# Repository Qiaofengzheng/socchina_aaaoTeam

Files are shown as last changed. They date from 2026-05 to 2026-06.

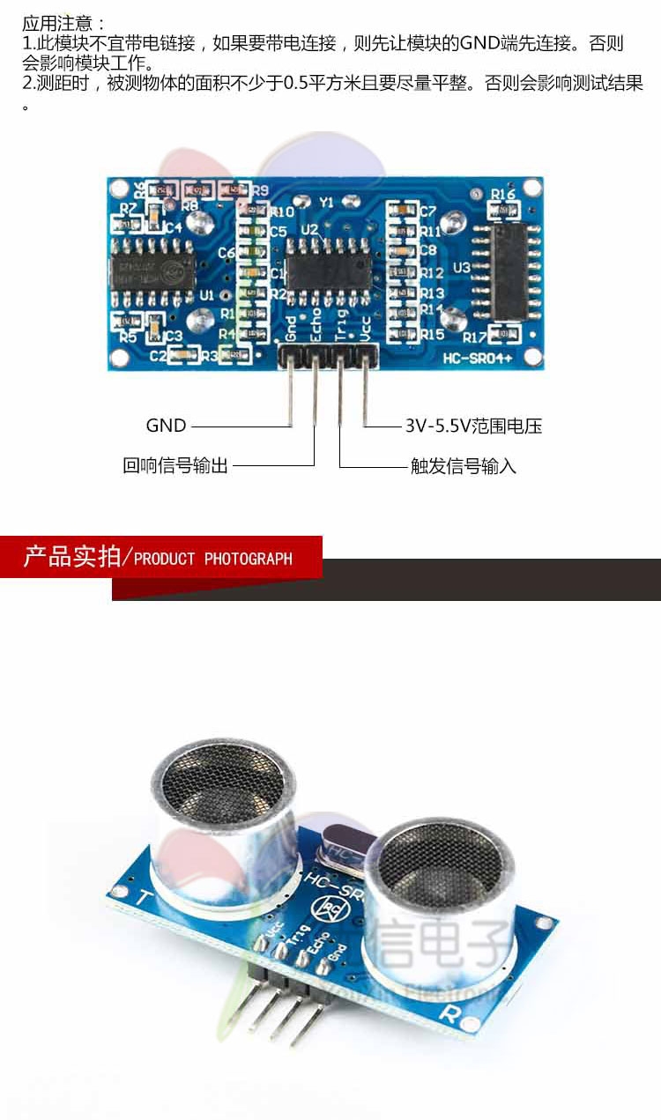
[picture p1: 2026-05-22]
竞赛资料/主控资料-ch32v307/CH32V307例程/2.24-HC-SR04超声波测距/2.24-HC-SR04超声波测距/2.jpg

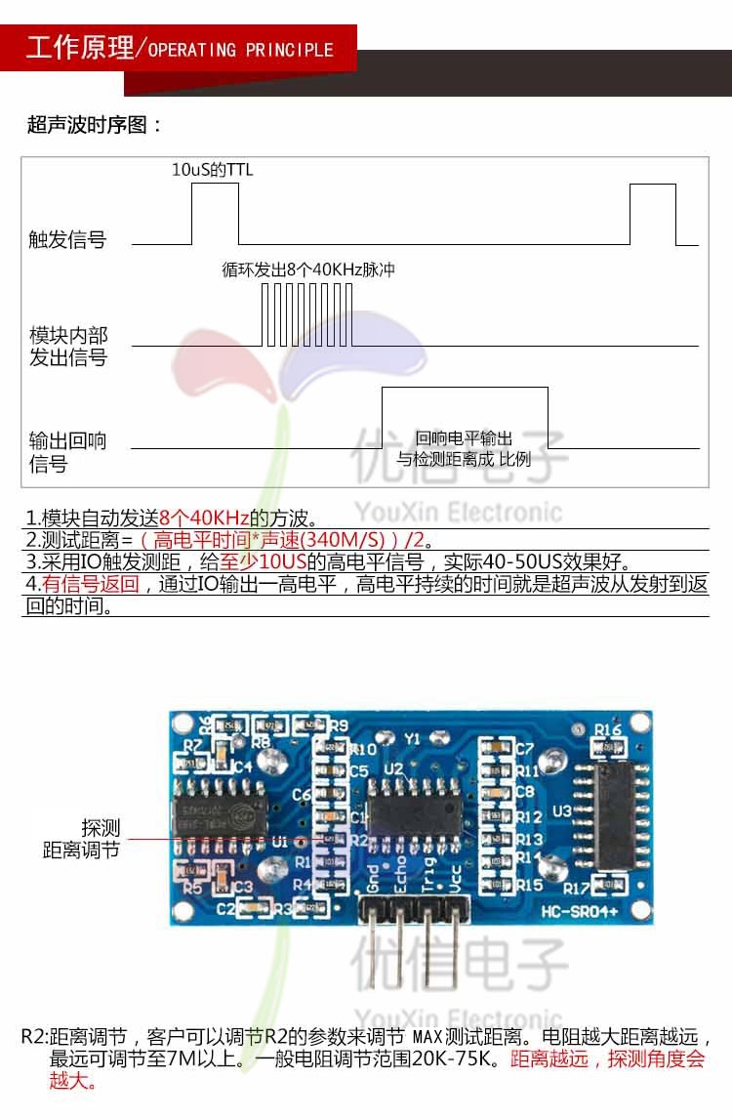
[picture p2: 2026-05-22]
竞赛资料/主控资料-ch32v307/CH32V307例程/2.24-HC-SR04超声波测距/2.24-HC-SR04超声波测距/1.jpg

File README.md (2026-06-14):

<div align="center">

# 🎥 基于CH32V307的稳像云台控制系统

### Multi-Modal Stabilized Gimbal Control System Based on CH32V307


[]()
[]()
[]()

*🏆 SOC China · AAAO Team*

---

## 📖 项目简介

本作品基于沁恒 **CH32V307** 核心板，设计了一款面向智能拍摄与辅助科技场景的**多模态交互三自由度稳像云台系统**。

系统通过摄像头实时采集图像，采用轻量化卷积神经网络实现**手势识别**与**人脸检测**，触发三自由度云台控制。创新性地集成**语音指令控制模块**与**低功耗蓝牙通信模块**，构建手势+语音+视觉的多模态人机交互体系，并采用**增量式PID算法**实现三轴舵机的精准控制。硬件上集成高扭矩舵机、OLED状态反馈模块、语音模块、低功耗蓝牙通信模块及独立电源，依托CH32V307的外设资源，通过多组UART串口实现识别指令与舵机控制的高效交互。创新点在于多模态指令映射、三轴协同控制、语音-视觉跨模态控制技术及低功耗边缘计算架构，适用于需要非接触控制的智能拍摄场景，以及益于特殊人群的辅助科技应用，兼具高实用性与可扩展性。

<div align="center">

### 🌟 核心亮点

| 🤚 手势控制 | 🗣️ 语音控制 | 👁️ 视觉跟踪 | 📱 蓝牙控制 |
|:---:|:---:|:---:|:---:|
| MediaPipe手势识别 | LD3320语音识别 | OpenCV人脸检测 | CH9141低功耗蓝牙 |
| 支持数字1-7及握拳 | 非接触语音指令 | 实时人脸追踪 | 手机APP远程控制 |

</div>

---

## 💡 项目背景与设计动机

### 为什么做这个项目？

在当今数字化时代，**摄像设备的智能化控制**已成为一个重要的技术方向。传统的云台控制方式——无论是手持遥控器还是手机APP——都要求操作者与设备保持物理接触或近距离操作。然而，在许多实际场景中，这种传统的交互方式存在明显的局限性：

1. **影视拍摄场景**：摄影师在进行多机位拍摄时，双手往往被其他设备占用，无法同时操控云台；在需要特殊角度拍摄时，操作者可能需要远离设备以获得更好的观察视角。

2. **无障碍辅助场景**：对于肢体残障人士而言，传统的按键式或触屏式交互方式可能无法使用。他们迫切需要一种**非接触式、直觉化**的人机交互方式来操控辅助设备。

3. **工业巡检场景**：在高温、高辐射、有毒等危险环境中，操作人员需要在安全距离外远程操控检测设备，传统的有线控制方式存在线缆束缚和信号延迟的问题。

4. **教育科研场景**：嵌入式系统、计算机视觉、控制理论等课程需要一个综合性的实践平台，让学生能够将理论知识应用于实际系统。

### 设计理念

基于上述需求分析，我们确立了以下设计原则：

- **多模态融合**：不依赖单一交互方式，而是同时支持手势、语音、视觉、蓝牙四种控制模式，用户可以根据场景灵活选择最合适的方式。
- **边缘计算优先**：将计算密集型任务（如图像识别）交给PC端处理，实时控制任务（如PID运算、舵机驱动）由嵌入式端完成，实现"边缘-云端"协同计算。
- **模块化架构**：硬件和软件均采用模块化设计，便于后期功能扩展和维护升级。
- **实时性保证**：关键控制路径采用中断驱动，确保从传感器输入到执行器输出的延迟最小化。

---

## 🏗️ 系统架构

### 总体架构设计

整个系统采用**分层架构**设计，自上而下分为三个层次：**感知决策层**（Python上位机）、**控制执行层**（CH32V307嵌入式系统）、**机械执行层**（三轴舵机云台）。各层之间通过标准化的串口协议进行数据交换，实现了高内聚、低耦合的系统架构。

```
+-------------------------------------------------------------------------+
|                   Python Upper Computer (PC)                            |
|                                                                         |
|  +----------------+  +----------------+  +----------------+            |
|  |   MediaPipe    |  |    OpenCV      |  |  Serial Comm   |            |
|  | Gesture Recog  |  | Face Detection |  | 3-Ch Parallel  |            |
|  | 21 Key Points  |  | Haar Cascade   |  | COM22/20/9     |            |
|  +--------+-------+  +--------+-------+  +--------+-------+            |
|           +------------------+--------------------+                      |
+-----------------------------------+--------------------------------------+
                                    | USB-UART
                                    v
+-------------------------------------------------------------------------+
|                 CH32V307 Embedded Control Layer                         |
|                                                                         |
|  +----------+  +----------+  +----------+  +----------+               |
|  |   UART   |  |   PID    |  |   PWM    |  |   GPIO   |               |
|  | Multi-Prt|--| 3-Axis   |--| Servo Drv|  |  Sensors |               |
|  |  Router  |  | Control  |  | 50Hz/3ch |  | ADC/GPIO |               |
|  +----------+  +----------+  +----------+  +----------+               |
|                                                                         |
|  +----------+  +----------+  +----------+  +----------+               |
|  |  Voice   |  |Bluetooth |  |   TFT    |  |  Buzzer  |               |
|  |  LD3320  |  |  CH9141  |  | Display  |  | + LED    |               |
|  +----------+  +----------+  +----------+  +----------+               |
+-------------------------------------------------------------------------+
                                    |
                                    v PWM 50Hz
+-------------------------------------------------------------------------+
|                      Mechanical Actuator Layer                          |
|                                                                         |
|       +--------------+  +--------------+  +--------------+             |
|       | X-Axis Servo |  | Y-Axis Servo |  | Z-Axis Servo |             |
|       |  PA0 (TIM2)  |  |  PA1 (TIM2)  |  |  PA2 (TIM2)  |             |
|       +--------------+  +--------------+  +--------------+             |
|                                                                         |
|                      +-------------------+                              |
|                      | 3-Axis Gimbal     |                              |
|                      | Stabilized Plat.  |                              |
|                      +-------------------+                              |
+-------------------------------------------------------------------------+
```

---

## 🎯 功能特性

### 🤚 多模态手势识别

手势识别是本系统最核心的交互方式之一。我们采用 Google 的 **MediaPipe** 框架作为手势识别引擎，该框架基于轻量化的卷积神经网络，能够在普通PC上实现实时的21点手部关键点检测。

**识别原理详解：**

MediaPipe 首先从视频帧中检测手部区域，然后定位21个手部关键点（包括指尖、指关节、手掌中心等）。通过分析这些关键点的空间位置关系，我们可以判断每根手指是否伸出：

- 对于拇指：比较指尖（关键点4）与拇指根部（关键点2）的水平位置关系
- 对于其他四指：比较指尖与对应掌指关节的垂直位置关系
- 如果指尖在手掌凸包外部，则认为该手指处于"伸出"状态

通过组合不同手指的伸出状态，系统可以识别出多种手势。为了提高识别的鲁棒性，我们还加入了**稳定性检测**机制：连续3帧识别到相同手势才确认为有效手势，避免因手部抖动导致的误识别。

支持 **7种手势** 识别，每种手势映射不同控制指令：

```
    +--------------------+
    |   Camera Input     |
    |  640x480 @ 30fps   |
    +--------+-----------+
             |
             v
    +--------------------+
    |   MediaPipe        |
    | Gesture Recognition|
    |   21 Key Points    |
    +--------+-----------+
             |
     +-------+-------+-------+
     |               |       |
     v               v       v
+----------+   +----------+  +----------+
|  Digit   |   |  Fist    |  |  Five    |
| 1/2/3/4  |   |  (Stop)  |  | (Track)  |
|  6/7     |   |          |  |          |
+----+-----+   +----+-----+  +----+-----+
     |              |             |
     v              v             v
 Manual Ctrl   Stop Motion    Start Face
 +/-5 deg                   Tracking Mode
```

**手势-功能映射表：**

| 手势 | 功能 | 云台动作 | 识别条件 |
|:---:|:---:|:---:|:---:|
| ☝️ 数字 `1` | X轴正转 | 水平向右 +5° | 仅食指伸出，关节角度>160° |
| ✌️ 数字 `2` | X轴反转 | 水平向左 -5° | 食指+中指伸出 |
| 🤟 数字 `3` | Y轴正转 | 垂直向上 +5° | 拇指+食指+中指伸出，指尖距离>60px |
| 🖐️ 数字 `4` | Y轴反转 | 垂直向下 -5° | 四指伸出（除小指） |
| 🖐️ 数字 `5` | 启动追踪 | 开启人脸跟踪模式 | 五指全部伸出 |
| 🤙 数字 `6` | Z轴正转 | 航向顺时针 +5° | 拇指+小指伸出（"打电话"手势） |
| 🤏 数字 `7` | Z轴反转 | 航向逆时针 -5° | 拇指+食指+中指伸出，指尖距离<60px |
| ✊ 握拳 `fist` | 停止 | 停止所有运动 | 无手指伸出 |

**防抖动与可靠性设计：**

由于手势识别存在一定的不确定性，我们在通信层面加入了多重保障机制：

1. **稳定性窗口**：连续3帧相同手势才触发指令发送
2. **冷却时间**：手势切换后需等待500ms才能触发下一次切换
3. **重复发送**：每个手势指令重复发送4次，确保嵌入式端能够接收到
4. **变化阈值**：人脸坐标变化超过5°才发送，减少通信负载

### 👁️ 智能人脸追踪

人脸追踪是本系统的另一核心功能。当用户做出"五指张开"手势或通过语音指令激活追踪模式后，系统会自动锁定摄像头画面中的人脸，并驱动云台跟随人脸运动，使人脸始终保持在画面中心区域。

**技术实现细节：**

1. **人脸检测**：采用 OpenCV 内置的 **Haar级联分类器**（`haarcascade_frontalface_default.xml`），这是一种经典的基于特征的机器学习检测方法。虽然近年来深度学习方法在准确率上有所超越，但Haar级联在嵌入式场景下具有**速度快、资源占用少**的优势，非常适合实时应用。

2. **目标选择策略**：当画面中存在多张人脸时，系统选择**面积最大的人脸**作为跟踪目标，这通常是距离摄像头最近、也是最可能需要被拍摄的主体。

3. **坐标映射算法**：将人脸中心的像素坐标转换为云台舵机的目标角度。具体来说：
   - 图像中心（320, 240）对应云台的中位角度（94°）
   - 人脸偏离图像中心越远，舵机需要偏转的角度越大
   - 映射公式：`angle = 94 - (center - image_center) * (86 / image_center)`

4. **平滑滤波**：为了消除人脸检测结果的帧间抖动，我们采用**5点移动平均滤波器**。具体做法是维护一个长度为5的滑动窗口，将最近5帧的人脸坐标取平均值作为最终输出。这样即使某一帧的检测结果存在偏差，也不会导致云台的突然跳动。

5. **三轴协同补偿**：在跟踪人脸时，不仅X轴和Y轴需要跟随运动，Z轴（航向）也需要进行协同补偿。当人脸偏向画面左侧时，Z轴需要顺时针旋转以获得更好的拍摄角度；反之亦然。补偿公式为：`z_compensation = norm_x × 20 + norm_y × 5`。

```
    +-------------------+
    | Gesture '5'       |
    | Five Fingers Open |
    +---------+---------+
              |
              v
    +-------------------+       +------------------+
    | Activate Tracking | <---- | Voice Command    |
    | Mode              |       | LD3320 Recognize |
    +---------+---------+       +------------------+
              |
              v
    +-------------------+
    |  Haar Cascade     |
    |  Face Detector    |
    +---------+---------+
              |
              v
    +-------------------+
    | Select Largest    |
    | Face Center (x,y) |
    +---------+---------+
              |
              v
    +-------------------+
    | Coord Mapping     |
    | Pixel -> Angle    |
    +---------+---------+
              |
              v
    +-------------------+
    | 5-Point Moving    |
    | Avg Smoothing     |
    +---------+---------+
              |
              v
    +-------------------+
    | 3-Axis PID Ctrl   |
    +---------+---------+
              |
              v
    +-------------------+
    | Servo Actuation   |
    | Gimbal Follow     |
    +-------------------+
```

### 🔊 语音控制系统

语音控制模块为系统提供了第三种交互维度。通过集成**LD3320**语音识别芯片，用户可以在不使用双手的情况下，通过简单的语音指令控制云台的行为。

**工作原理：**

LD3320是一款专用的语音识别芯片，内置了非特定人语音识别引擎（即不需要对特定用户进行训练）。芯片通过UART串口与CH32V307通信，当识别到预设的语音关键词后，会通过串口发送对应的识别码。

**系统中的语音控制流程：**

1. 用户说出语音指令（如"开始追踪"）
2. LD3320芯片识别语音，通过UART5发送识别结果给CH32V307
3. CH32V307接收到识别结果后，通过UART4转发给Python上位机
4. Python上位机收到指令后，启动或关闭人脸追踪模式

这种**语音→嵌入式→PC**的跨层级控制链路，实现了语音-视觉的跨模态融合控制。

```
    +----------------+
    |  Voice Input   |
    | 'Start Tracking'|
    +-------+--------+
            |
            v
    +----------------+
    |   LD3320       |
    | Voice Recog    |
    +-------+--------+
            |
            v
    +----------------+
    |    UART5       |
    | Intpt Receive  |
    +-------+--------+
            |
            v
    +----------------+
    |    UART4       |
    | Fwd to Python  |
    +-------+--------+
            |
            v
    +----------------+
    |    Python      |
    | Activate Track |
    +----------------+
```

### 📱 蓝牙远程控制

通过集成**CH9141**低功耗蓝牙模块，系统支持手机APP远程控制。用户可以通过蓝牙连接，实时查看传感器数据、调整控制参数、切换工作模式。

**蓝牙通信协议：**

蓝牙模块通过UART6与CH32V307通信，采用简单的命令-响应协议：

| 命令码 | 功能描述 |
|:---:|:---|
| `1` | 查看CO气体浓度（MQ7传感器） |
| `2` | 查看天然气浓度（MQ4传感器） |
| `3` | 查看测距数据 |
| `5` | 查看温度数据 |
| `6` | 查看湿度数据 |
| `7` | 当前模式阈值 -1 |
| `8` | 当前模式阈值 +1 |
| `9` | 全部传感器数据上报 |

蓝牙模块每500ms通过TIM10定时中断自动读取一次数据，确保控制指令的及时响应。

---

## 🛠️ 硬件配置

### 核心芯片选型

本系统选用**CH32V307VCT6**作为主控芯片，这是沁微科技推出的一款基于**RISC-V**架构的32位通用微控制器。选择该芯片主要基于以下考量：

1. **高性能**：主频高达144MHz，能够满足实时控制的计算需求
2. **丰富的外设**：集成了多路UART、SPI、I2C、ADC、PWM等外设，无需额外扩展芯片
3. **充足的存储**：256KB Flash + 64KB SRAM，为复杂的控制算法提供了足够的运行空间
4. **开源生态**：RISC-V架构具有开放的指令集和丰富的社区资源，便于开发和调试
5. **成本优势**：相比同级别的ARM芯片，CH32V307具有更好的性价比

<table>
  <tr>
    <td><b>主控芯片</b></td>
    <td>CH32V307VCT6 (RISC-V, 144MHz)</td>
  </tr>
  <tr>
    <td><b>系统时钟</b></td>
    <td>144 MHz</td>
  </tr>
  <tr>
    <td><b>Flash</b></td>
    <td>256 KB</td>
  </tr>
  <tr>
    <td><b>SRAM</b></td>
    <td>64 KB</td>
  </tr>
  <tr>
    <td><b>舵机驱动</b></td>
    <td>3路PWM (TIM2, 50Hz, 0.5ms-2.5ms)</td>
  </tr>
  <tr>
    <td><b>通信接口</b></td>
    <td>5路UART + SPI + I2C + ADC</td>
  </tr>
</table>

### 完整硬件清单

| 类别 | 型号/规格 | 数量 | 用途说明 |
|:---:|:---|:---:|:---|
| 🔲 主控板 | CH32V307VCT6 核心板 | 1 | 系统主控制器，运行所有嵌入式程序 |
| ⚙️ 舵机 | MG996R 高扭矩舵机 | 3 | X/Y/Z三轴驱动，扭矩11kg·cm |
| 📷 摄像头 | USB摄像头 (640×480@30fps) | 1 | 手势识别和人脸检测的视觉输入 |
| 🔊 语音模块 | LD3320 语音识别模块 | 1 | 非特定人语音识别，UART接口 |
| 📡 蓝牙模块 | CH9141 低功耗蓝牙模块 | 1 | 手机APP远程控制，UART接口 |
| 🖥️ 显示屏 | TFT180 (128×160) | 1 | 系统状态显示、坐标信息反馈 |
| 🔔 蜂鸣器 | 有源蜂鸣器 | 1 | 操作提示音、报警信号 |
| 💡 LED指示灯 | 直插LED | 2 | 系统状态指示 |
| 🔥 火焰传感器 | 红外火焰传感器 | 1 | 火焰检测（GPIO输入） |
| 🌫️ 气体传感器 | MQ2/MQ4/MQ7 | 3 | 烟雾/天然气/CO浓度检测（ADC输入） |
| 🔌 电源模块 | 5V/3A 开关电源 | 1 | 系统供电 |

### 引脚分配图

```
                            CH32V307VCT6
                         ┌────────────────┐
            UART1_TX ◀──┤PA9         PA0├──▶ X-Servo  (TIM2_CH1)
            UART1_RX ◀──┤PA10        PA1├──▶ Y-Servo  (TIM2_CH2)
                        ┤PA2         PA2├──▶ Z-Servo  (TIM2_CH3)
            UART8_TX ◀──┤PC4         PA4├──▶ Buzzer
            UART8_RX ◀──┤PC5         PA3├──◀ Flame Sensor
                        ┤              ├
           UART4_TX  ◀──┤PC10        PB0├──◀ ADC Sensor 1
           UART4_RX  ◀──┤PC11        PB1├──◀ ADC Sensor 2
           UART5_TX  ◀──┤PC12        PC0├──◀ ADC Sensor 3
           UART5_RX  ◀──┤PD2         PC1├──◀ ADC Sensor 4
           UART6_TX  ◀──┤PE10        PC2├──◀ ADC Sensor 5
           UART6_RX  ◀──┤PE11        PC3├──◀ ADC Sensor 6
                        ┤              ├
             SPI_CS  ◀──┤PA4         PB13├──▶ SPI_SCK
           SPI_MOSI  ◀──┤PB15        PB6├──▶ I2C_SCL (PCA9685)
                        ┤PB7         PB7├──▶ I2C_SDA (PCA9685)
                        ┤              ├
            LED_1    ◀──┤PC13       PB10├──▶ LED_2
                        └────────────────┘
```

### UART 串口分配

本系统的一个显著特点是使用了**5路UART串口**进行并行通信，每路串口负责不同的通信任务。这种设计虽然增加了硬件复杂度，但实现了各通信通道的**独立性和实时性**，避免了单总线通信可能带来的数据冲突和延迟问题。

<table>
  <thead>
    <tr>
      <th>串口</th>
      <th>波特率</th>
      <th>TX</th>
      <th>RX</th>
      <th>用途</th>
      <th>详细说明</th>
    </tr>
  </thead>
  <tbody>
    <tr>
      <td><b>UART_4</b></td>
      <td>115200</td>
      <td>PC10</td>
      <td>PC11</td>
      <td>🖥️ Python主通信</td>
      <td>与PC端Python程序的主通信通道，传输手势指令和语音触发信号</td>
    </tr>
    <tr>
      <td><b>UART_5</b></td>
      <td>9600</td>
      <td>PC12</td>
      <td>PD2</td>
      <td>🔊 语音识别模块</td>
      <td>连接LD3320语音识别芯片，接收语音识别结果</td>
    </tr>
    <tr>
      <td><b>UART_6</b></td>
      <td>115200</td>
      <td>PE10</td>
      <td>PE11</td>
      <td>👁️ 人脸坐标接收</td>
      <td>接收Python发送的人脸坐标数据，格式为"X,Y\n"</td>
    </tr>
    <tr>
      <td><b>UART_8</b></td>
      <td>9600</td>
      <td>PC4</td>
      <td>PC5</td>
      <td>🗣️ 语音控制模块</td>
      <td>连接外部语音控制模块，接收语音控制指令</td>
    </tr>
    <tr>
      <td><b>UART_1</b></td>
      <td>19200</td>
      <td>PA9</td>
      <td>PA10</td>
      <td>📡 调试/反馈</td>
      <td>用于调试信息输出和温度数据反馈</td>
    </tr>
  </tbody>
</table>

---

## 💻 软件架构

### 代码结构

整个项目的代码按照功能模块划分为清晰的目录结构，遵循**高内聚、低耦合**的设计原则：

```
📁 CH32V307 的稳像云台控制系统/
├── 📄 README.md                    # 项目说明文档
├── 📄 .gitignore                   # Git忽略配置
│
├── 📁 竞赛资料/
│   ├── 📁 代码/
│   │   ├── 📄 识别.py              # 🐍 Python上位机 (504行)
│   │   │                              负责手势识别、人脸检测、串口通信
│   │   │
│   │   ├── 📄 语音控制.hd           # 🔊 语音控制配置文件
│   │   │
│   │   └── 📁 ch32v307代码/
│   │       ├── 📁 libraries/       # 📚 SDK库文件 (第三方)
│   │       │   ├── zf_common/      #   通用工具库 (延时、调试等)
│   │       │   ├── zf_device/      #   设备驱动库 (摄像头、屏幕等)
│   │       │   └── zf_driver/      #   底层驱动库 (UART、PWM、GPIO等)
│   │       │
│   │       └── 📁 project/
│   │           ├── 📁 code/        # 📝 用户核心代码 (17个源文件)
│   │           │   ├── main.c           # 程序入口，主循环
│   │           │   ├── duoji.c/h        # 舵机控制、命令处理
│   │           │   ├── pid.c/h          # PID控制算法
│   │           │   ├── contorl.c/h      # 控制逻辑、数据处理
│   │           │   ├── bluetooth.c/h    # 蓝牙通信控制
│   │           │   ├── ironhand.c/h     # 多串口数据路由
│   │           │   ├── init.c/h         # 系统初始化
│   │           │   ├── servo.c/h        # PWM舵机驱动
│   │           │   ├── adc.c/h          # ADC多通道采集
│   │           │   ├── beep.c/h         # 蜂鸣器驱动
│   │           │   ├── led.c/h          # LED驱动
│   │           │   ├── spi.c/h          # 软件SPI驱动
│   │           │   ├── myiic.c/h        # 模拟I2C驱动
│   │           │   ├── pca9685.c/h      # PCA9685驱动 (备用)
│   │           │   ├── temp.c/h         # 内部温度传感器
│   │           │   ├── light_sensor.c/h # 光照传感器 (预留)
│   │           │   └── font.h           # 字体字模数据
│   │           │
│   │           └── 📁 user/
│   │               └── 📁 src/
│   │                   ├── main.c       # 主程序入口
│   │                   └── isr.c        # 中断服务程序 (489行)
│   │
│   └── 📁 主控资料-ch32v307/         # 芯片数据手册、参考设计
│
└── 📁 项目介绍/
    ├── 📄 作品报告.pdf               # 详细技术报告
    └── 📄 演示视频.mp4               # 系统演示视频
```

### 模块功能说明

#### 核心模块详解

| 模块 | 文件 | 代码行数 | 核心职责 |
|:---:|:---:|:---:|:---|
| **主程序** | `main.c` | 55 | 系统初始化、主循环调度 |
| **舵机控制** | `duoji.c` | 282 | 三轴舵机角度控制、手势命令处理、平滑移动算法 |
| **PID控制** | `pid.c` | 50 | 增量式PID算法实现（备用，当前使用分段比例控制） |
| **控制逻辑** | `contorl.c` | 431 | 坐标解析、数据滤波、蓝牙数据发送、传感器采集 |
| **蓝牙通信** | `bluetooth.c` | 158 | CH9141蓝牙模块控制、命令状态机 |
| **多串口路由** | `ironhand.c` | 245 | 5路UART数据接收、语音命令转发 |
| **中断服务** | `isr.c` | 489 | UART/Timer/EXTI中断处理 |
| **系统初始化** | `init.c` | 48 | 外设初始化、参数配置 |
| **舵机驱动** | `servo.c` | 28 | PWM信号生成、角度-脉宽转换 |
| **Python上位机** | `识别.py` | 504 | MediaPipe手势识别、OpenCV人脸检测、串口通信 |

---

## 🧮 核心算法详解

### 1️⃣ PID控制算法

PID（比例-积分-微分）控制是工业控制中最经典的算法之一。本系统为X/Y/Z三个轴分别配置了独立的PID控制器，每个轴的参数根据其运动特性进行了专门调校。

**算法公式：**

```
    误差(error) = 目标角度 - 当前角度
    
    P (比例项) = Kp × error
        → 对误差进行比例响应，误差越大响应越强
    
    I (积分项) = Ki × Σerror (带积分限幅)
        → 消除稳态误差，当|error|<10°时才累积积分
        → 当|error|≥10°时清零积分，防止积分饱和
    
    D (微分项) = Kd × (error - prev_error)
        → 预测误差变化趋势，抑制超调和振荡
    
    输出 = P + I + D (带输出限幅)
```

**三轴PID参数配置：**

| 轴 | Kp | Ki | Kd | 积分限幅 | 输出限幅 | 设计意图 |
|:---:|:---:|:---:|:---:|:---:|:---:|:---|
| X轴 | 1.2 | 0.04 | 0.1 | 30.0 | 10.0 | 快速响应，适配水平旋转的低惯量特性 |
| Y轴 | 0.8 | 0.03 | 0.2 | 40.0 | 8.0 | 平稳移动，避免垂直方向的重力影响导致抖动 |
| Z轴 | 0.8 | 0.05 | 0.2 | 20.0 | 5.0 | 精确控制，航向微调需要更高的精度 |

### 2️⃣ 分段比例控制（实际使用）

在实际调试中，我们发现对于本系统的舵机响应特性，**分段比例控制**比完整的PID控制更加适合。这是因为：

1. 舵机本身具有位置保持能力，不需要积分项来消除稳态误差
2. 舵机的响应速度有限，微分项的预测作用不明显
3. 分段控制可以根据误差大小自动切换响应速度，更加符合人机交互的直觉

**分段策略：**

```
+---------------------------------------------------------------+
|               Segmented Proportional Control                  |
+---------------------------------------------------------------+
|                                                               |
|   |error| > 20   =>  step = error / 2   (Fast Chase)         |
|                     Large error: full speed toward target     |
|                                                               |
|   |error| > 5    =>  step = error / 3   (Medium Speed)       |
|                     Medium error: slow down to avoid overshoot|
|                                                               |
|   |error| <= 5   =>  step = +/-1        (Fine Tune)          |
|                     Small error: adjust by 1 deg per cycle    |
|                                                               |
+---------------------------------------------------------------+
```

这种分段策略的优点是：**大误差时快速响应，小误差时精细控制**，既保证了系统的动态性能，又提高了定位精度。

### 3️⃣ 三轴协同控制算法

在人脸跟踪模式下，三个轴不是独立运动的，而是需要协同配合。特别是Z轴（航向），需要根据X/Y轴的偏移量进行补偿，以获得最佳的拍摄角度。

**协同补偿公式：**

```
    X-Axis Offset --+
                    |
                    +--> Z-Axis Compensation = norm_x * 20 + norm_y * 5
    Y-Axis Offset --+

    Where:
    - norm_x = (face_x - 135) / 135.0  (normalized to [-1, 1])
    - norm_y = (face_y - 120) / 120.0  (normalized to [-1, 1])
    - Z-Axis initial angle = 40 deg
    - Compensation coefficients 20 and 5 tuned by field testing
```

### 4️⃣ 语音-视觉跨模态控制

本系统的一个创新点是实现了**语音-视觉跨模态控制**。用户可以通过语音指令激活视觉追踪模式，然后系统自动切换到人脸跟踪控制，实现"语音触发、视觉执行"的无缝切换。

```
    Voice Command --> Activate Visual Tracking --> Face Detection --> Gimbal Follow
        |
        +--> "Start Tracking" --> Python starts tracking mode
            "Stop Tracking"  --> Close tracking mode
```

### 5️⃣ 低功耗边缘计算架构

本系统采用"边缘-云端"协同计算架构，将不同计算需求的任务分配到最合适的计算节点：

```
+-------------------------------------------+
|        Edge Node (CH32V307)                |
|                                            |
|   144MHz RISC-V Processor                  |
|   ├── PID Control (realtime, <1ms)         |
|   ├── Sensor Data Acquisition (realtime)   |
|   ├── Serial Data Routing (realtime)       |
|   └── PWM Servo Drive (50Hz)               |
|                                            |
|        Cloud Node (PC)                     |
|                                            |
|   Python + GPU Acceleration                |
|   ├── MediaPipe Gesture (~30ms/frame)      |
|   ├── OpenCV Face Detection (~20ms/frame)  |
|   └── Image Preprocessing & Coord Calc     |
|                                            |
+-------------------------------------------+
```

这种架构的优势在于：
- **实时性**：嵌入式端专注于实时控制，不受图像处理延迟的影响
- **灵活性**：PC端可以随时更新识别算法，无需重新烧录固件
- **可扩展性**：未来可以将图像识别算法移植到嵌入式端，实现完全独立运行

---

## 📡 通信协议详解

### Python ↔ CH32V307 通信协议

Python上位机与CH32V307之间通过3路串口并行通信，每路串口承载不同的数据类型：

| 通信方向 | 串口 | 数据格式 | 示例 | 说明 |
|:---:|:---:|:---|:---|:---|
| Python → MCU | COM22 | `{数字}\n` | `"5\n"` | 手势指令（1-7, 0=停止） |
| Python → MCU | COM20 | `{X},{Y}\n` | `"94,120\n"` | 人脸坐标（角度值） |
| MCU → Python | COM9 | `5` | `'5'` | 语音触发信号 |

### 手势指令编码

| 指令码 | ASCII | 手势 | 云台动作 |
|:---:|:---:|:---:|:---|
| `0` | 0x30 | 握拳 | 停止所有运动 |
| `1` | 0x31 | 数字1 | X轴 +5° |
| `2` | 0x32 | 数字2 | X轴 -5° |
| `3` | 0x33 | 数字3 | Y轴 +5° |
| `4` | 0x34 | 数字4 | Y轴 -5° |
| `5` | 0x35 | 数字5 | 启动人脸追踪 |
| `6` | 0x36 | 数字6 | Z轴 +5° |
| `7` | 0x37 | 数字7 | Z轴 -5° |

---

## 📱 应用场景

### 🎬 智能拍摄

在影视制作、直播、Vlog拍摄等场景中，操作者可以通过手势或语音控制摄像头的拍摄角度，无需接触任何控制设备。特别是当摄影师需要同时操控多个机位时，多模态控制的优势尤为突出。

**典型使用流程：**
1. 摄影师做出"五指张开"手势，激活人脸追踪模式
2. 摄像头自动锁定目标人物，云台跟随其运动
3. 需要调整拍摄角度时，通过语音指令"左转"、"右转"进行微调
4. 拍摄结束后，做出"握拳"手势，停止所有运动

### 🏥 辅助科技

对于肢体残障人士，传统的交互方式可能无法使用。本系统提供的非接触式控制方式，为他们打开了一扇新的窗户。

**无障碍应用场景：**
- 手指轻微活动即可控制云台方向
- 语音指令替代复杂的按键操作
- 人脸追踪实现"看哪拍哪"的直觉式控制

### 🎓 教学实验

本系统涵盖了嵌入式系统、计算机视觉、控制理论、通信协议等多个领域的知识点，非常适合作为综合性课程设计或毕业设计的实践平台。

**可学习的知识点：**
- RISC-V架构与嵌入式C编程
- PID控制算法原理与调参
- 串口通信协议设计
- 计算机视觉基础（手势识别、人脸检测）
- 多传感器数据融合

---

## ⚡ 快速开始

### 环境要求

| 工具 | 版本要求 | 用途 |
|:---|:---|:---|
| MounRiver Studio | V1.8.1+ | 嵌入式代码编译与烧录 |
| Python | 3.8+ | 上位机运行环境 |
| OpenCV | 4.5+ | 图像处理库 |
| MediaPipe | 0.8+ | 手势识别框架 |
| PySerial | 3.5+ | 串口通信库 |

### 1. 硬件连接

按照上述引脚分配图完成硬件连接，特别注意：
- 三路舵机分别连接PA0/PA1/PA2
- 各UART模块的TX/RX需要交叉连接
- 确保电源供电充足（舵机工作电流较大）

### 2. 嵌入式端编译与烧录

```bash
# 1. 打开 MounRiver Studio
# 2. 导入项目: 竞赛资料/代码/ch32v307代码/project
# 3. 编译项目 (Build)
# 4. 连接开发板，烧录固件
```

### 3. Python上位机运行

```bash
# 1. 安装依赖
pip install opencv-python mediapipe pyserial numpy

# 2. 修改串口配置（根据实际设备号）
# 在 识别.py 中修改：
#   serial_hand = init_serial('COM22', 9600)   # 手势串口
#   serial_face = init_serial('COM20', 115200) # 人脸串口
#   serial_mcu  = init_serial('COM9', 115200)  # MCU通信串口

# 3. 运行程序
python 识别.py
```

### 4. 操作说明

1. 系统启动后，摄像头窗口自动打开
2. 在摄像头前做出手势，观察云台响应
3. 做出"五指张开"手势激活人脸追踪
4. 做出"握拳"手势停止所有运动
5. 按'q'键退出程序

---

## 📊 技术指标

| 指标 | 数值 | 说明 |
|:---|:---|:---|
| 系统时钟 | 144 MHz | CH32V307主频 |
| 图像分辨率 | 640×480 | 摄像头采集分辨率 |
| 视频帧率 | 30 fps | 摄像头采集帧率 |
| 手势识别延迟 | ~100ms | 3帧确认时间 |
| 人脸检测延迟 | ~30ms | 单帧检测时间 |
| PID控制周期 | 20ms | 嵌入式端控制频率 |
| 数据发送周期 | 100ms | Python端发送频率 |
| 舵机PWM频率 | 50Hz | 标准舵机控制频率 |
| 舵机角度范围 | 0°-180° | 三轴统一范围 |
| 蓝牙通信距离 | ~10m | 低功耗蓝牙有效距离 |

---

## 🗺️ 未来改进方向

| 方向 | 具体措施 | 预期效果 |
|:---|:---|:---|
| 🧠 边缘AI | 将手势识别算法移植到嵌入式端 | 脱离PC独立运行 |
| 📷 更换摄像头 | 使用OV2640等嵌入式摄像头 | 降低系统成本 |
| 🔋 电池供电 | 加入锂电池管理模块 | 实现便携式使用 |
| 🌐 WiFi控制 | 替换蓝牙为WiFi模块 | 扩大控制距离 |
| 📊 数据可视化 | 开发专用APP实时显示传感器数据 | 提升用户体验 |
| 🤖 自动构图 | 基于AI的智能构图算法 | 自动调整拍摄角度 |

---

## 📋 Git 提交规范

本项目遵循以下 Git 提交规范，确保代码版本管理的清晰和可追溯：

| 类型 | 说明 | 示例 |
|:---:|:---|:---|
| `feat` | 新功能 | `feat: 添加蓝牙远程控制功能` |
| `fix` | Bug修复 | `fix: 修复UART6数据接收丢包问题` |
| `docs` | 文档更新 | `docs: 更新README项目说明` |
| `refactor` | 代码重构 | `refactor: 优化PID控制算法结构` |
| `perf` | 性能优化 | `perf: 减少串口通信延迟` |
| `test` | 测试相关 | `test: 添加舵机角度映射单元测试` |
| `chore` | 构建/工具 | `chore: 更新.gitignore配置` |

**提交信息格式：**
```
<type>: <简短描述>

<详细说明（可选）>

<相关Issue编号（可选）>
```

---

## 🐛 已知问题与改进方向

| 类别 | 问题描述 | 影响 | 改进方案 |
|:---:|:---|:---:|:---|
| 🐛 Bug | `adc_data`数组越界（声明5元素，访问[5]） | 高 | 修改数组大小为6 |
| 🐛 Bug | `contorl.c`文件名拼写错误 | 低 | 重命名为`control.c` |
| 🧹 清理 | 大量注释代码未清理 | 低 | 删除或使用条件编译 |
| 🧹 清理 | `STC11XX.H`与CH32V307无关 | 低 | 移除冗余文件 |
| 📝 规范 | 全局变量命名不规范（如i1,i2,i3） | 中 | 结构化封装，使用有意义的命名 |
| 📝 规范 | 中文注释乱码（编码问题） | 低 | 统一使用UTF-8编码 |
| 🔄 优化 | PID已初始化但未在主循环中使用 | 中 | 集成PID控制替代分段比例控制 |

---

## 📚 参考资料

- [CH32V307 官方数据手册](https://www.wch.cn/products/CH32V307.html)
- [MediaPipe Hands 文档](https://google.github.io/mediapipe/solutions/hands.html)
- [OpenCV Haar Cascades](https://docs.opencv.org/4.x/db/d28/tutorial_cascade_classifier.html)
- [PID控制算法详解](https://en.wikipedia.org/wiki/PID_controller)
- [PCA9685 16通道PWM驱动器](https://www.nxp.com/docs/en/datasheet/PCA9685.pdf)

---

## 📄 开源许可

本项目基于 [MIT License](LICENSE) 开源。

---

## 👥 团队信息

<div align="center">

**AAAO Team**

<table>
  <tr>
    <td align="center"><b>项目成员</b></td>
    <td align="center"><b>联系方式</b></td>
    <td align="center"><b>GitHub</b></td>
  </tr>
  <tr>
    <td>Qiaofengzheng</td>
    <td>2247142231@qq.com</td>
    <td><a href="https://github.com/Qiaofengzheng">@Qiaofengzheng</a></td>
  </tr>
</table>

---

⭐ 如果这个项目对你有帮助，请给个Star支持一下！

<div align="center">

**Made with ❤️ by AAAO Team**

</div>

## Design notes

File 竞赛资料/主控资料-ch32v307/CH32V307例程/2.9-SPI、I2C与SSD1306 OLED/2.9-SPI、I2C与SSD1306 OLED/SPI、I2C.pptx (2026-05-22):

## SPI

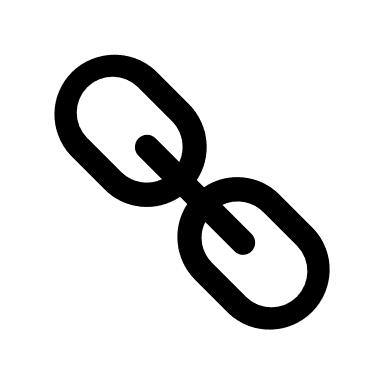
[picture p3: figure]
链接

## 常用SPI库函数手册

- void SPI_Init(SPI_TypeDef *SPIx, SPI_InitTypeDef *SPI_InitStruct);
- void SPI_Cmd(SPI_TypeDef *SPIx, FunctionalState NewState);
- void SPI_I2S_SendData(SPI_TypeDef *SPIx, uint16_t Data);
- uint16_t SPI_I2S_ReceiveData(SPI_TypeDef* SPIx);
- FlagStatus SPI_I2S_GetFlagStatus(SPI_TypeDef *SPIx, uint16_t SPI_I2S_FLAG);

## 常用SPI库函数手册

void SPI_Init(SPI_TypeDef *SPIx, SPI_InitTypeDef *SPI_InitStruct);
描述 | 根据指定参数初始化SPIx外围设备。
SPIx | SPI号
SPI_InitStruct | 原型： typedef struct { uint16_t SPI_Direction; uint16_t SPI_Mode; uint16_t SPI_DataSize; uint16_t SPI_CPOL; uint16_t SPI_CPHA; uint16_t SPI_NSS; uint16_t SPI_BaudRatePrescaler; uint16_t SPI_FirstBit; uint16_t SPI_CRCPolynomial; }SPI_InitTypeDef;

## 常用SPI库函数手册

void SPI_Init(SPI_TypeDef *SPIx, SPI_InitTypeDef *SPI_InitStruct);
SPI_InitStruct | SPI_Direction：指定SPI单向或双向数据模式，可选 SPI_Direction_2Lines_FullDuplex//2线全双工 SPI_Direction_2Lines_RxOnly//2线只接收 SPI_Direction_1Line_Rx//1线接收 SPI_Direction_1Line_Tx//1线发送 SPI_Mode：指定SPI模式，可选 SPI_Mode_Master SPI_Mode_Slave SPI_DataSize：指定SPI数据帧长度，可选 SPI_DataSize_16b SPI_DataSize_8b SPI_CPOL：可选SPI_CPOL_Low或SPI_CPOL_High SPI_CPHA：可选SPI_CPHA_1Edge或SPI_CPHA_2Edge SPI_NSS：指定硬件NSS还是软件NSS，可选SPI_NSS_Soft或SPI_NSS_Hard

## 常用SPI库函数手册

void SPI_Init(SPI_TypeDef *SPIx, SPI_InitTypeDef *SPI_InitStruct);
SPI_InitStruct | SPI_BaudRatePrescaler：时钟预分频器值，时钟来自于主时钟，可选 SPI_BaudRatePrescaler_x，其中x(2,4,8,16,32,64,128,256) SPI_FirstBit：指定数据传输是从MSB位还是LSB位开始，可选 SPI_FirstBit_MSB//高位在前 SPI_FirstBit_LSB//低位在前 SPI_CRCPolynomial：指定用于CRC计算的多项式。
FlagStatus SPI_I2S_GetFlagStatus(SPI_TypeDef *SPIx, uint16_t SPI_I2S_FLAG);
描述 | 检查是否设置了指定的SPI/I2S标志位。
返回值 | 标志位是否置位（SET/RESET）
SPI_I2S_FLAG | SPI_I2S_FLAG_TXE//SPI/I2S发送缓存为空标志位 SPI_I2S_FLAG_RXNE//SPI/I2S发送缓存非空标志位 SPI_I2S_FLAG_BSY//SPI/I2S忙碌标志位 SPI_I2S_FLAG_OVR//SPI/I2S溢出标志位 SPI_FLAG_MODF//SPI模式错误标志位 SPI_FLAG_CRCERR//SPI CRC错误标志位

## SPI初始化代码（SPI3为例）

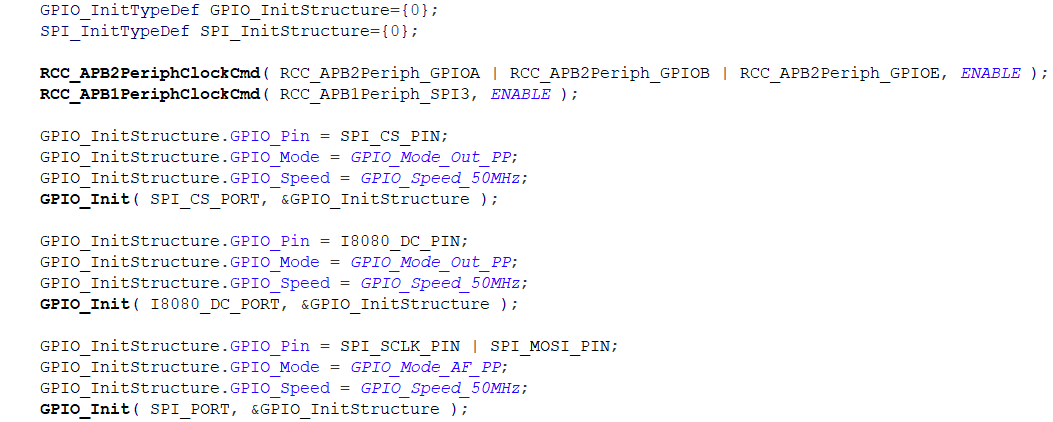
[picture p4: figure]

## SPI初始化代码（SPI3为例）

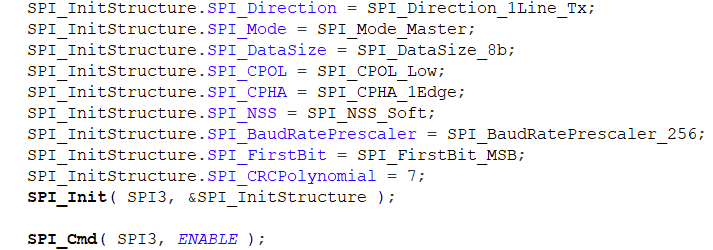
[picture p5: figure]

## I2C

## 常用I2C库函数手册

- void I2C_Init(I2C_TypeDef *I2Cx, I2C_InitTypeDef *I2C_InitStruct);
- void I2C_Cmd(I2C_TypeDef *I2Cx, FunctionalState NewState);
- void I2C_AcknowledgeConfig(I2C_TypeDef *I2Cx, FunctionalState NewState);
- void I2C_GenerateSTART(I2C_TypeDef *I2Cx, FunctionalState NewState);
- void I2C_GenerateSTOP(I2C_TypeDef *I2Cx, FunctionalState NewState);
- void I2C_Send7bitAddress(I2C_TypeDef *I2Cx, uint8_t Address, uint8_t I2C_Direction);
- void I2C_SendData(I2C_TypeDef *I2Cx, uint8_t Data);
- uint8_t I2C_ReceiveData(I2C_TypeDef *I2Cx);
- FlagStatus I2C_GetFlagStatus(I2C_TypeDef *I2Cx, uint32_t I2C_FLAG);
- ErrorStatus I2C_CheckEvent(I2C_TypeDef *I2Cx, uint32_t I2C_EVENT);

## 常用I2C库函数手册

void I2C_Init(I2C_TypeDef *I2Cx, I2C_InitTypeDef *I2C_InitStruct);
描述 | 根据指定参数初始化I2Cx外围设备。
I2Cx | I2C号
I2C_InitStruct | 原型： typedef struct { uint32_t I2C_ClockSpeed; uint16_t I2C_Mode; uint16_t I2C_DutyCycle; uint16_t I2C_OwnAddress1; uint16_t I2C_Ack; uint16_t I2C_AcknowledgedAddress; }I2C_InitTypeDef; I2C_ClockSpeed：I2C时钟频率，必须低于400kHz I2C_Mode：I2C模式，可选 I2C_Mode_I2C//I2C模式 I2C_Mode_SMBusDevice//SMBus从设备 I2C_Mode_SMBusHost//SMBus主设备

## 常用I2C库函数手册

void I2C_Init(I2C_TypeDef *I2Cx, I2C_InitTypeDef *I2C_InitStruct);
I2C_InitStruct | I2C_DutyCycle：指定I2C快速模式占空比，可选 I2C_DutyCycle_16_9//I2C快速模式tL/tH=16/9 I2C_DutyCycle_2//I2C快速模式tL/tH=2 I2C_OwnAddress1：本机I2C地址 I2C_Ack：启用或禁用应答位，可选 I2C_Ack_Enable//启用应答位 I2C_Ack_Disable//禁用应答位 I2C_AcknowledgedAddress：寻址模式，可选 I2C_AcknowledgedAddress_7bit//7位地址模式 I2C_AcknowledgedAddress_10bit//10位地址模式

## 常用I2C库函数手册

void I2C_AcknowledgeConfig(I2C_TypeDef *I2Cx, FunctionalState NewState);
描述 | 启用或禁用指定的I2C应答功能。
void I2C_GenerateSTART(I2C_TypeDef *I2Cx, FunctionalState NewState);//生成起始信号 void I2C_GenerateSTOP(I2C_TypeDef *I2Cx, FunctionalState NewState);//生成终止信号
void I2C_Send7bitAddress(I2C_TypeDef *I2Cx, uint8_t Address, uint8_t I2C_Direction);
描述 | 发送7位地址来寻找从机
I2C_Direction | I2C方向，可选 I2C_Direction_Transmitter I2C_Direction_Receiver
FlagStatus I2C_GetFlagStatus(I2C_TypeDef *I2Cx, uint32_t I2C_FLAG);
返回值 | 标志位是否置位（SET/RESET）
I2C_FLAG | I2C_FLAG_BUSY//总线忙标志位 I2C_FLAG_AF//应答失败标志位 I2C_FLAG_BERR//总线错误标志位 I2C_FLAG_TXE//发送数据寄存器空标志位 I2C_FLAG_RXNE//接收寄存器非空标志位

## 常用I2C库函数手册

FlagStatus I2C_GetFlagStatus(I2C_TypeDef *I2Cx, uint32_t I2C_FLAG);
I2C_FLAG | I2C_FLAG_BTF//字节发送完成标志位 I2C_FLAG_SB//起始位标志位（主模式）
ErrorStatus I2C_CheckEvent(I2C_TypeDef *I2Cx, uint32_t I2C_EVENT);
返回值 | 错误状态（ERROR/SUCCESS）
I2C_EVENT | I2C事件，可选 I2C_EVENT_MASTER_MODE_SELECT - EV5. I2C_EVENT_MASTER_TRANSMITTER_MODE_SELECTED - EV6. I2C_EVENT_MASTER_RECEIVER_MODE_SELECTED - EV6. I2C_EVENT_MASTER_BYTE_RECEIVED - EV7. I2C_EVENT_MASTER_BYTE_TRANSMITTING - EV8. I2C_EVENT_MASTER_BYTE_TRANSMITTED - EV8_2. I2C_EVENT_MASTER_MODE_ADDRESS10 - EV9.

## I2C初始化代码（I2C2为例）

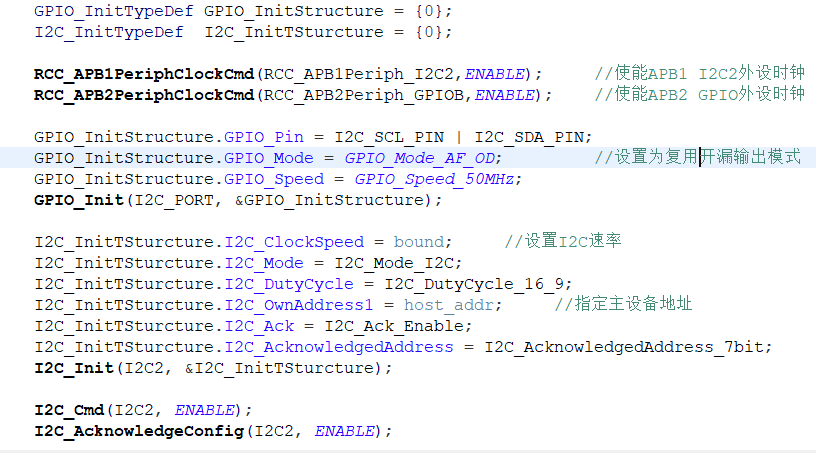
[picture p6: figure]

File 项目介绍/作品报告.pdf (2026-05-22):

## 《基于 CH32V307 的稳像云台控制系统》

摘要

本作品基于沁恒 CH32V307 核心板，设计并实现了一款集多模态交互的三 自由度稳像云台控制系统。系统通过摄像头实时采集图像数据，采用轻量化卷积 神经网络（CNN）实现 7 类手势分类及人脸追踪功能，结合增量式 PID 算法驱 动高扭矩舵机完成三轴协同运动。创新性地融合 ASR-PRO 语音指令模块与低功 耗蓝牙通信技术，构建了手势+语音+视觉的混合交互体系，支持 1m 内无接触式 控制。硬件上采用模块化设计，集成三自由度云台机械结构、OLED 状态反馈屏、 多路 UART 串口外设及独立电源管理单元，充分发挥 CH32V307 芯片的硬件加 速能力，实现边缘端低延迟数据处理。
系统的核心创新点体现在三个方面：首先，提出多模态指令动态映射机制， 实现语音、手势与视觉指令的无冲突切换，例如语音命令“开始跟踪”可即时激 活人脸跟随模式，同时 TFT 屏显示“track”状态；其次，采用 PID 控制算法， 对人脸坐标预测补偿，提高舵机角度分辨率；最后，构建跨模态协同架构，通过 蓝牙 BleUart 实现手机端实时接收坐标参数（如模式 5 下的人脸位置数据），结 合内置温度传感器（-40℃~+85℃监测范围）实现过热预警，形成完整的闭环控 制链路。
在应用层面，系统可便捷应用于三大场景：智能拍摄领域，通过手势控制 X/Y/Z 轴±5°精准调姿，满足特殊角度拍摄需求；辅助科技领域，作为残障人 士交互接口，实现"语音唤醒+手势微调"的复合操作模式；远程协作场景，在 10m 蓝牙范围内稳定传输视频会议中的发言人跟踪数据。
本设计仍可进行模块化拓展以及产品优化，一方面，其支持快速扩展陀螺仪、 环境光传感器等外设；另一方面，采用的轻量化 CNN 模型可优化 RISC-V 平台 边缘计算。未来可通过学习进一步提升多设备协同跟踪能力，或接入云端平台实 现大数据驱动的运动参数优化，在无人机稳像、VR 交互等领域具有广阔应用前 景。

关键词：多模态交互；轻量化卷积神经网络（CNN）；增量式 PID 算法；三自由 度云台机械结构；

目录

第一部分 作品概述

### 1.1 功能与特性

本作品是一款融合多模态交互的三自由度稳像云台控制系统。其主要功能包 括：
(1) 智能手势控制：通过手势指令，系统可进行无接触式操作，控制三轴舵 机各个轴的正向反向转动，实现精细化控制舵机角度。
(2) 人脸识别并跟随：通过人脸识别计算坐标，并使用串口通信，单片机端 解析后，采用增量式 PID 算法驱动三轴舵机相互协调，跟随人脸坐标的改变而运 动。
(3) 语音指令控制：采用 ASR-PRO 语音识别控制模块，实现语音控制三轴舵 机开启人脸跟随模式，便于无接触式控制；以及对于系统温度状态的监控，温度 过高时，便于及时做出响应。
(4) 移动端实时接收数据：通过手机软件 BleUart 与蓝牙模块的连接，实时 接收并记录坐标参数信息，实现信息集成。

### 1.2 应用领域

该系统主要应用于智能拍摄、远程协作、辅助科技等领域：
(1) 智能拍摄：可广泛应用于专业摄影、直播及影视拍摄场景。通过手势控 制和人脸跟踪功能，实现无接触式相机运镜，同时也适合单人创作团队 或特殊角度拍摄需求。提升拍摄效率与创意空间。
(2) 辅助科技：作为残障人士的人机交互接口，通过语音和手势即可控制设 备转向或跟拍，提升生活自主性。
(3) 远程协作：在视频会议、远程医疗等场景中，系统可自动跟踪发言人面 部，保持画面稳定。避免操作人员频繁接触设备，符合无菌环境要求。

### 1.3 主要技术特点

(1) 多模态交互融合：集成手势识别、语音控制和人脸跟踪技术，通过 UART 串口实现多模块高效协同，支持手势+语音+视觉的混合指令输入，提升 人机交互灵活性与场景适应性。
(2) 高精度三轴协同控制：采用增量式 PID 算法驱动三轴舵机，结合轻量化 CNN 模型实时处理图像数据，确保云台动态跟踪稳定性。
(3) 低功耗边缘计算架构：基于 RISC-V 芯片 CH32V307 的硬件加速能力， 本地完成图像识别与运动控制，减少数据传输延迟；蓝牙模块实现移动 端数据同步，降低功耗。

### 1.4 主要性能指标

性能 | 指标
跟踪精度 | 人脸/手势识别角度误差≤±1.5°，舵机控制分辨率达 0.5°， 静态稳像抖动幅度＜0.3°。
响应速度 | 从指令输入到舵机响应的延迟＜200ms，人脸跟踪模式下动态 调整频率≥15Hz。
多模态识别率 | 手势识别准确率≥95%（7 类手势），语音指令识别率≥92%， 支持 1m 内有效交互。
测温精度 | 内置传感器及 ADC 模块测温，范围 -40℃ ~ +85℃，精度至小 数点后三位。
通信性能 | 蓝牙传输距离≥10m，串口指令传输速率 115200bps。

### 1.5 主要创新点

(1) 多模态融合交互技术：创新性地将手势识别、语音控制和人脸跟踪相结 合，在低功耗 RISC-V 平台上实现高实时性交互，突破传统云台单一控 制方式的局限性。
(2) 三轴协同自适应 PID 控制：通过动态调整舵机扭矩分配，有效抑制过冲 和机械谐振。结合人脸坐标预测补偿，提升复杂运动下的稳定性。

### 1.6 设计流程

(1) 需求分析：确定三自由度稳像云台控制系统的功能需求和应用场景。
(2) 方案设计：进行系统整体架构设计，确定各模块功能，通过识别后进行功能 展示。
(3) 软件开发：编写数据处理、控制和用户接口等软件模块。
(4) 系统集成：将硬件与软件进行集成，完善运行，进行系统调试。
(5) 测试与优化：对系统进行全面测试，优化性能。 第二部分 系统组成及功能说明

### 2.1 整体介绍

系统整体框图如下：

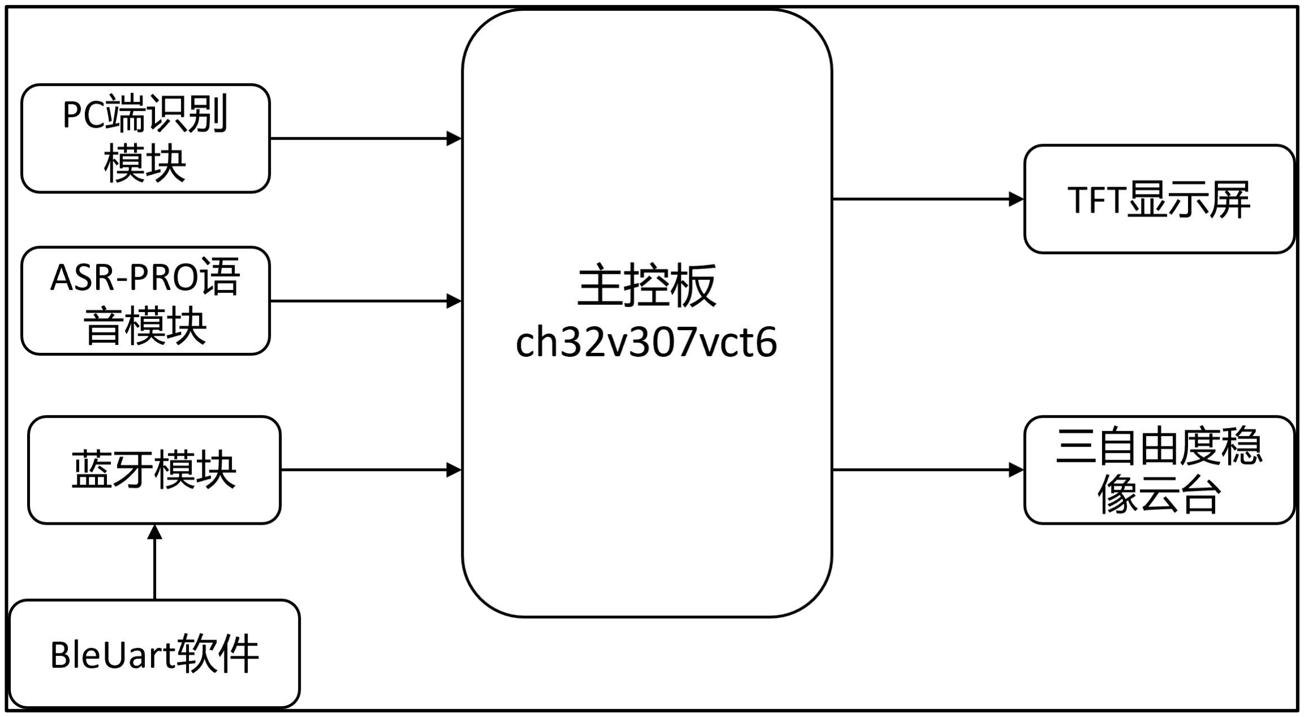
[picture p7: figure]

图 1 系统整体框图
电脑端运行识别的 python 代码，识别到手势或者人脸后，模式数据以及跟 踪模式下的人脸坐标传输至主控板，并展现在 TFT 显示屏上，同时三轴舵机在 相应的模式下运动（数字 1，2，3，4，6，7 分别控制 X、Y、Z 轴的正向反向转 动，数字 5 开启人脸跟踪）；
运用 ASR-PRO 语音模块，通过“小云”唤醒系统，当识别到“开始跟踪” 时，开启人脸跟踪模式，同时数据传输至 TFT 显示屏；当识别到“温度状态” 时，启用单片机内置温度传感器和 ADC 模块，进行温度读取并播报状态； 手机端运用 BleUart 软件通过连接蓝牙，用以接收并记录跟踪状态模式下的 参数；

### 2.2 硬件系统介绍

### 2.2.1 硬件整体介绍

硬件系统主要包括 5 个模块，通过语音模块以及蓝牙模块，进行系统控制， 三自由度云台在相应的控制下展现不同姿态。

三自由度云台 | CH9141K 蓝牙模块 | TFT 显示屏 | ASR-PRO 语音模块

### 2.2.2 电路各模块及机械设计介绍

下图为系统各模块与主控的设计连接情况，其中通过设计的 PCB 板完成初

步的线路连接，进而实现各功能。

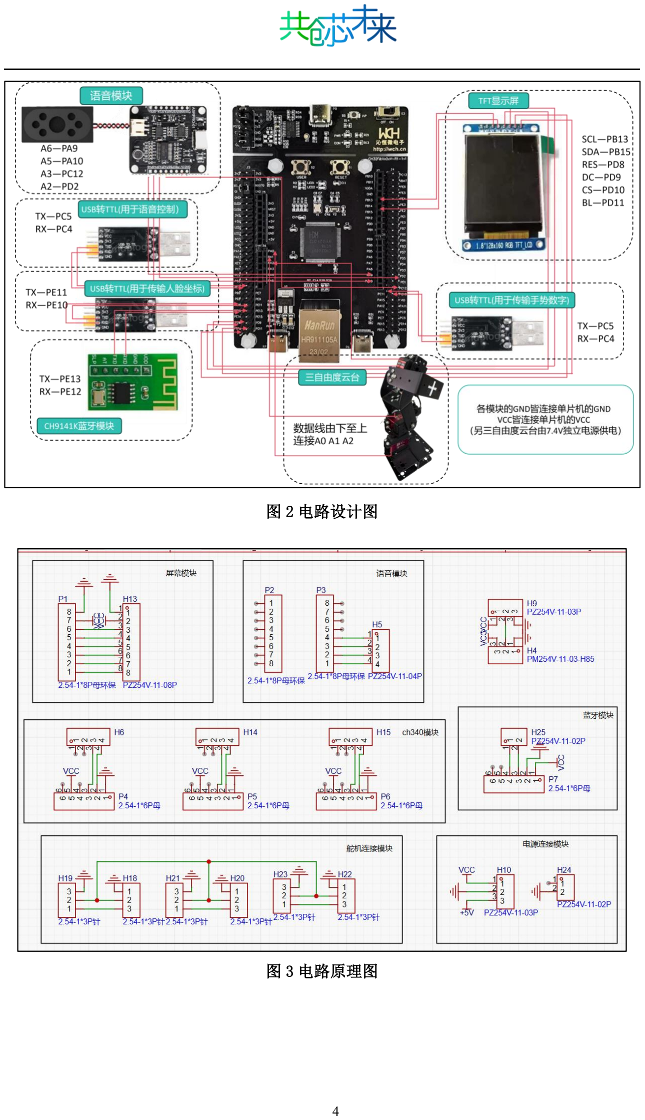
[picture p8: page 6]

图 2 电路设计图

图 3 电路原理图

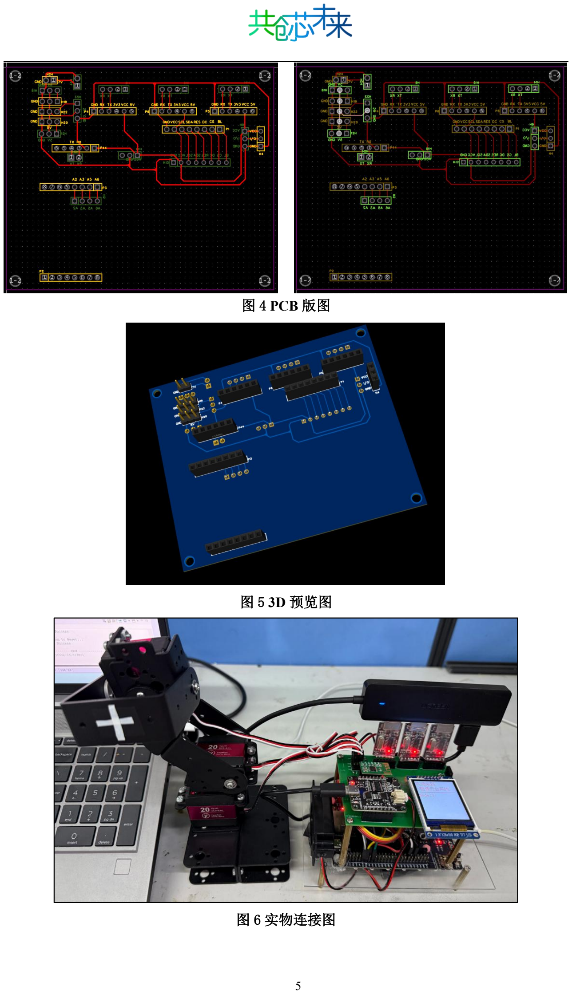
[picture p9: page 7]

图 4 PCB 版图

图 5 3D 预览图

图 6 实物连接图

### 2.3 软件系统介绍

### 2.3.1 软件整体介绍

软件系统包括 PC 端控制程序，手机端控制程序，语音设计程序。
- PC 端控制程序：运行 python 代码进行数字手势以及人脸识别，从而控制稳 像云台系统。

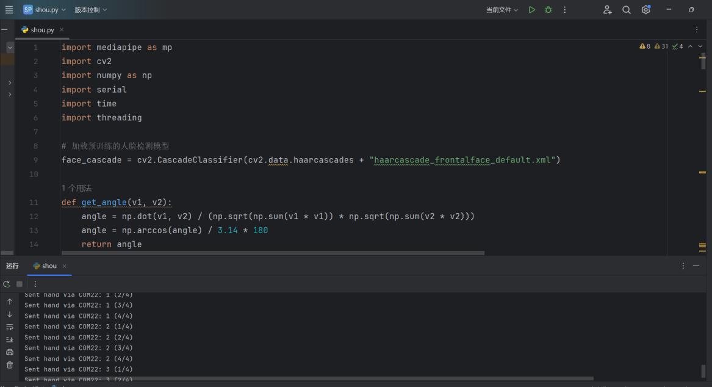
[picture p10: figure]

图 7 PC 端控制程序
- 手机端控制程序：使用 BleUart 软件，在各个模式下，进行数据的接收，各 种状态下数据如下。

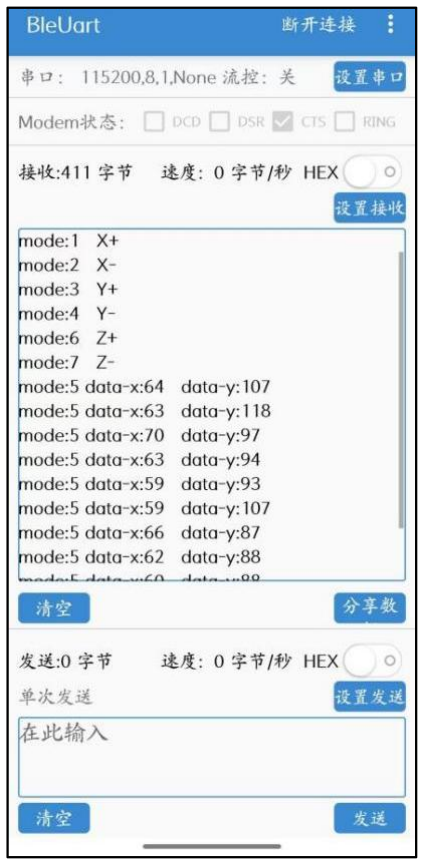
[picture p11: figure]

图 8 手机端初始界面

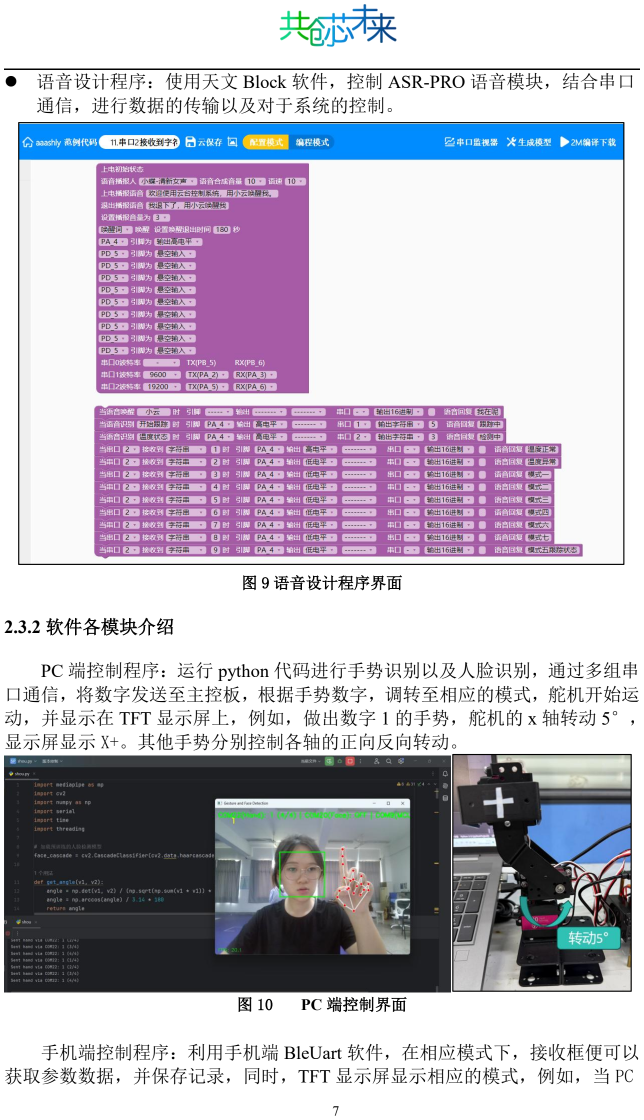
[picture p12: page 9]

- 语音设计程序：使用天文 Block 软件，控制 ASR-PRO 语音模块，结合串口 通信，进行数据的传输以及对于系统的控制。

图 9 语音设计程序界面

### 2.3.2 软件各模块介绍

PC 端控制程序：运行 python 代码进行手势识别以及人脸识别，通过多组串 口通信，将数字发送至主控板，根据手势数字，调转至相应的模式，舵机开始运 动，并显示在 TFT 显示屏上，例如，做出数字 1 的手势，舵机的 x 轴转动 5°， 显示屏显示 X+。其他手势分别控制各轴的正向反向转动。

图 10 PC 端控制界面

手机端控制程序：利用手机端 BleUart 软件，在相应模式下，接收框便可以 获取参数数据，并保存记录，同时，TFT 显示屏显示相应的模式，例如，当 PC

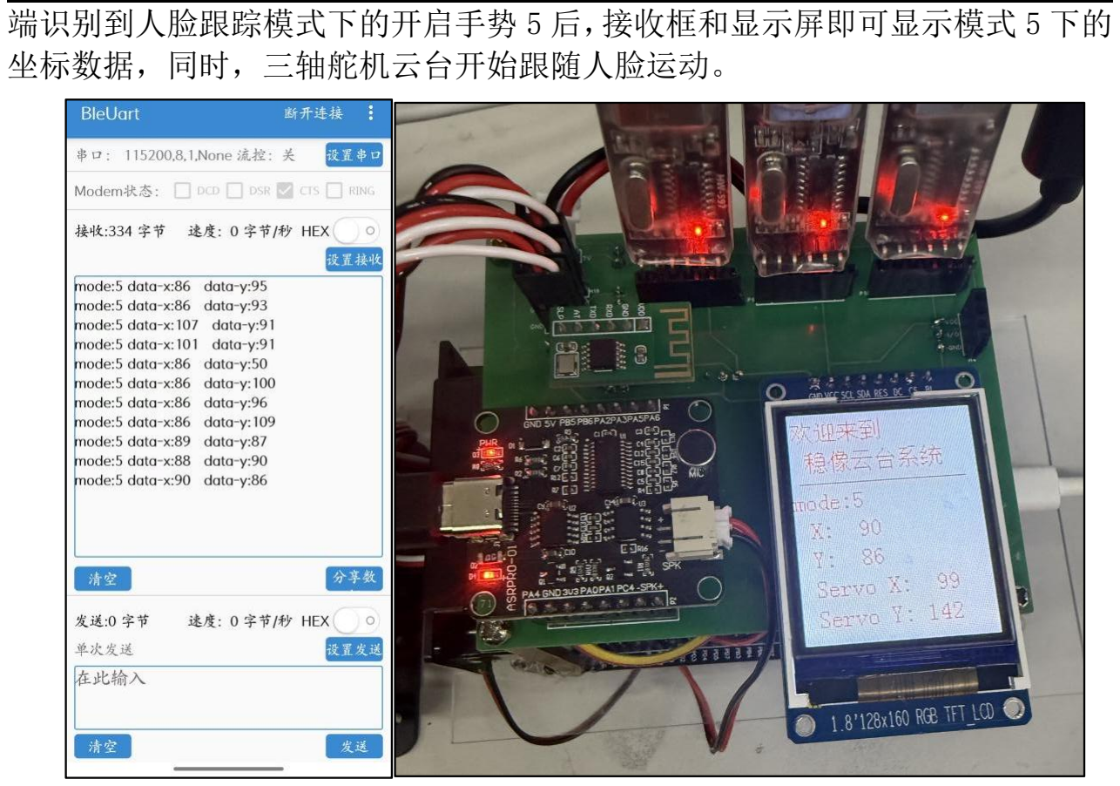
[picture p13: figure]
端识别到人脸跟踪模式下的开启手势 5 后，接收框和显示屏即可显示模式 5 下的 坐标数据，同时，三轴舵机云台开始跟随人脸运动。

图 11 手机端接收数据显示界面

语音设计模块：利用天问 Block 软件进行编程，主要功能是识别特定语音后 开启模式 5 的跟踪状态，对于各模块的播报，以及对于系统温度的监控。例如， 当识别到“开始跟踪”的语音后，屏幕显示“track”，即开始人脸跟踪。

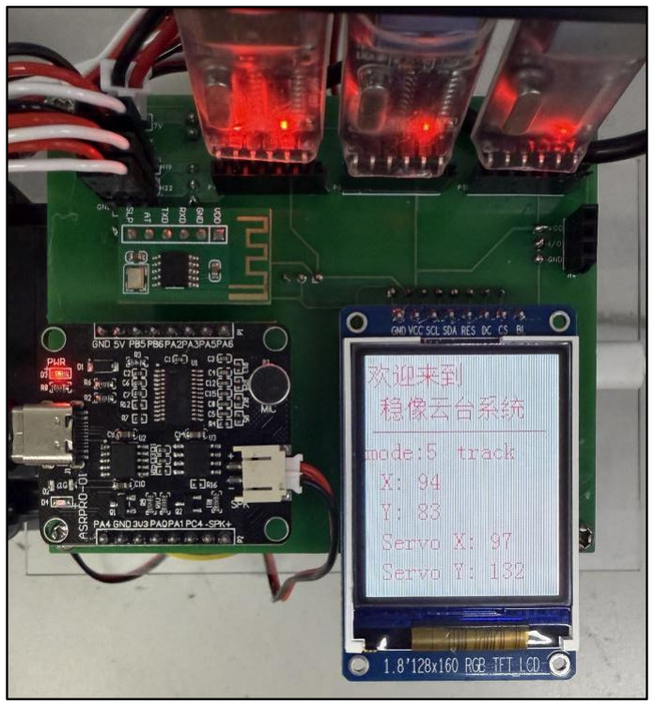
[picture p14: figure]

图 12 语音模式功能显示图

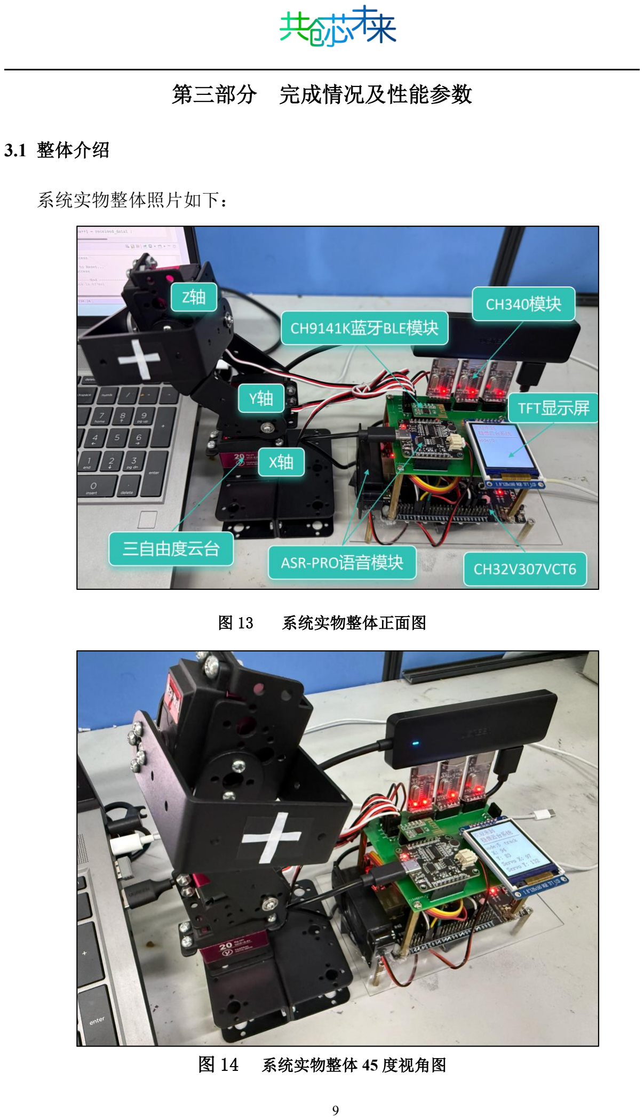
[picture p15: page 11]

第三部分 完成情况及性能参数

### 3.1 整体介绍

系统实物整体照片如下：

图 13 | 系统实物整体正面图
图 14 | 系统实物整体 45 度视角图

## 3.2.1 机械成果

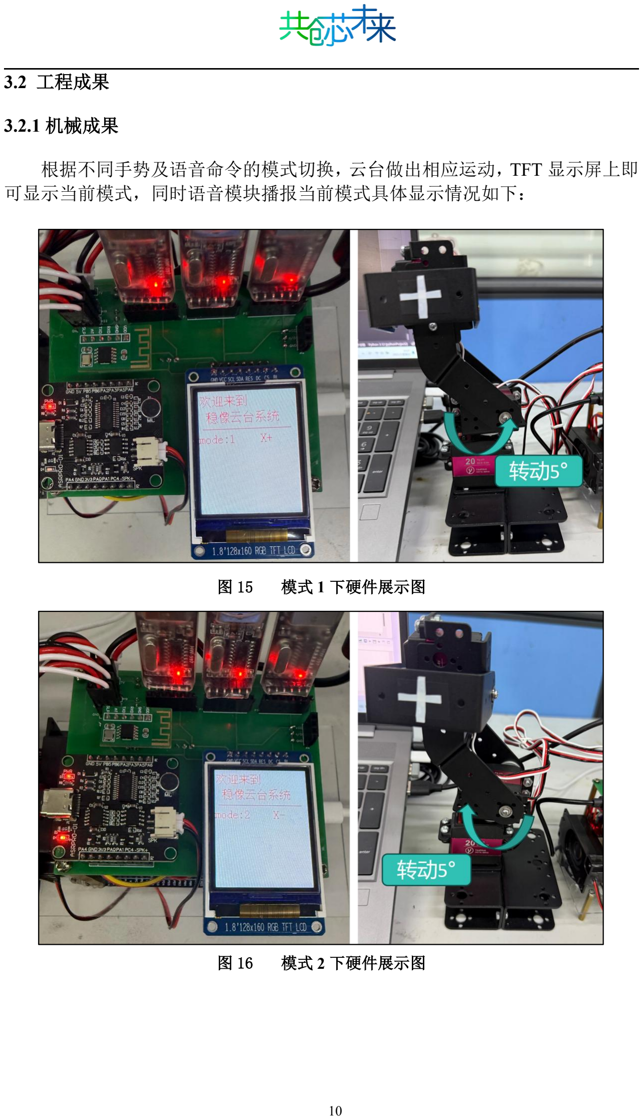
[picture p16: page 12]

### 3.2 工程成果

根据不同手势及语音命令的模式切换，云台做出相应运动，TFT 显示屏上即 可显示当前模式，同时语音模块播报当前模式具体显示情况如下：

图 15 | 模式 1 下硬件展示图
图 16 | 模式 2 下硬件展示图

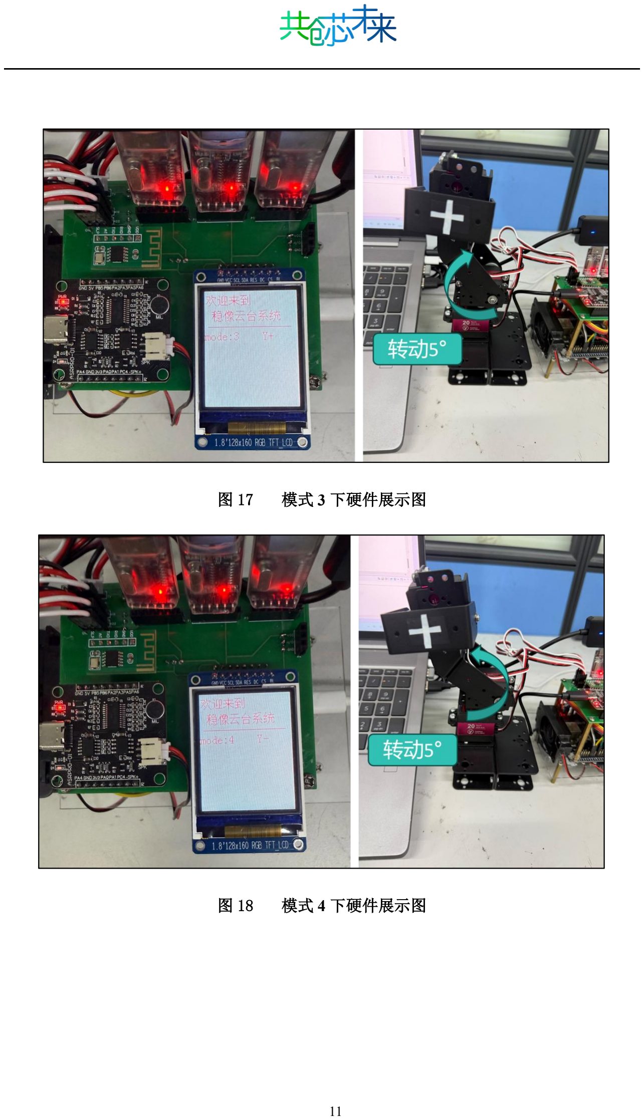
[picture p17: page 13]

图 17 | 模式 3 下硬件展示图
图 18 | 模式 4 下硬件展示图

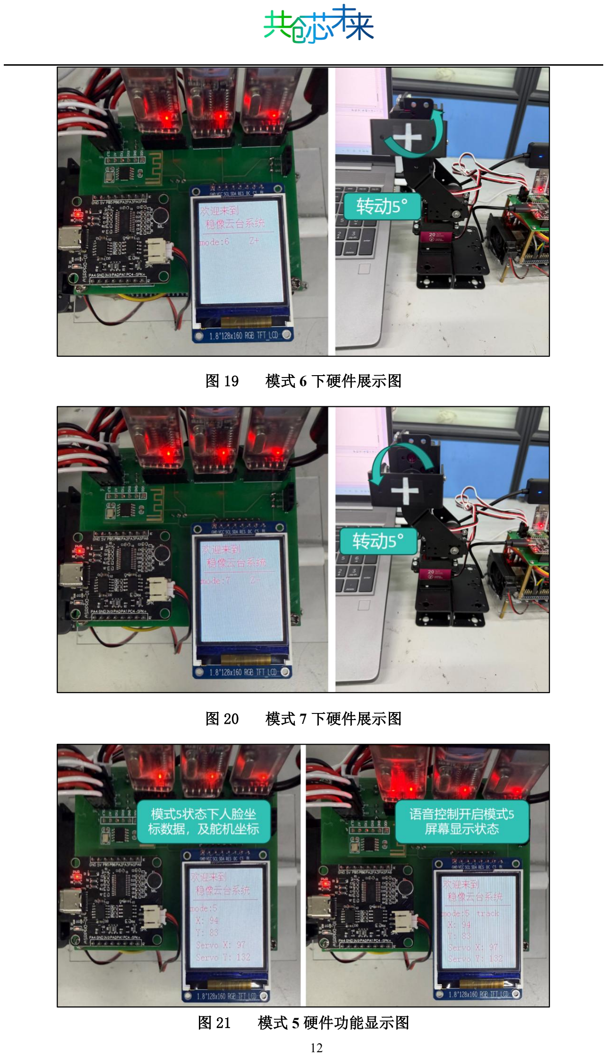
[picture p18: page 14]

图 19 | 模式 6 下硬件展示图
图 20 | 模式 7 下硬件展示图
图 21 | 模式 5 硬件功能显示图

## 3.2.2 软件成果

通过任意的数字手势识别，电脑端会将识别的数字以串口通信的方式，识别 到信息后连续发送四次给核心板，同时 TFT 显示屏跳转至相应的模式界面，实 现了系统无接触式操作。当语音模块接收到语音信息后，通过串口通信使 PC 端 触发与手势 5 相同的命令，即开始人脸跟踪模式。

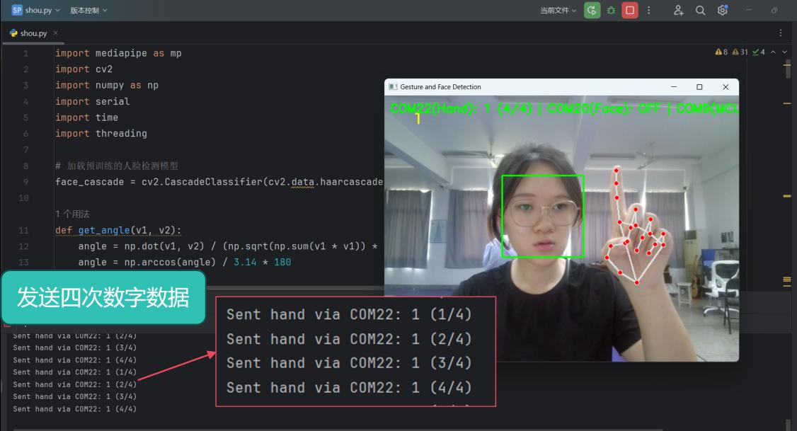
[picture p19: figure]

图 22 | 手势 1 下软件展示图

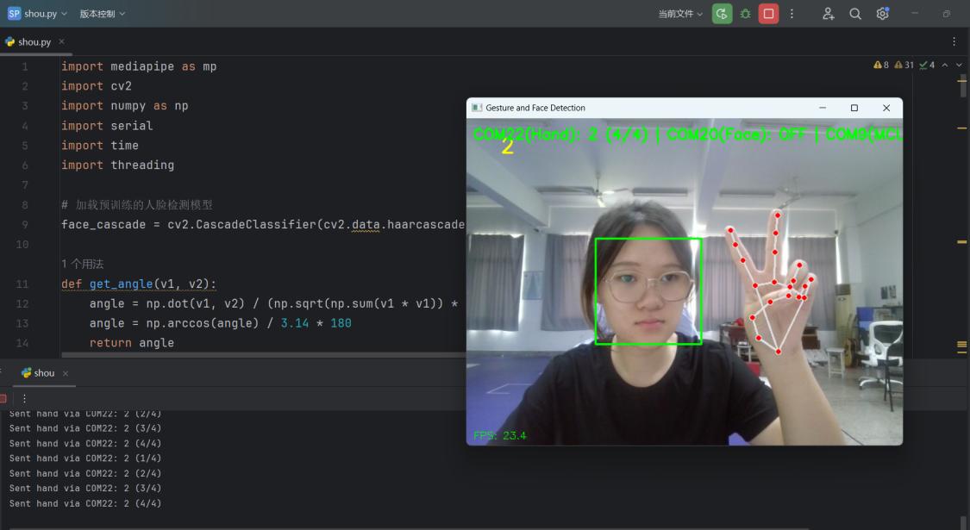
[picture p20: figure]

图 23 | 手势 2 下软件展示图

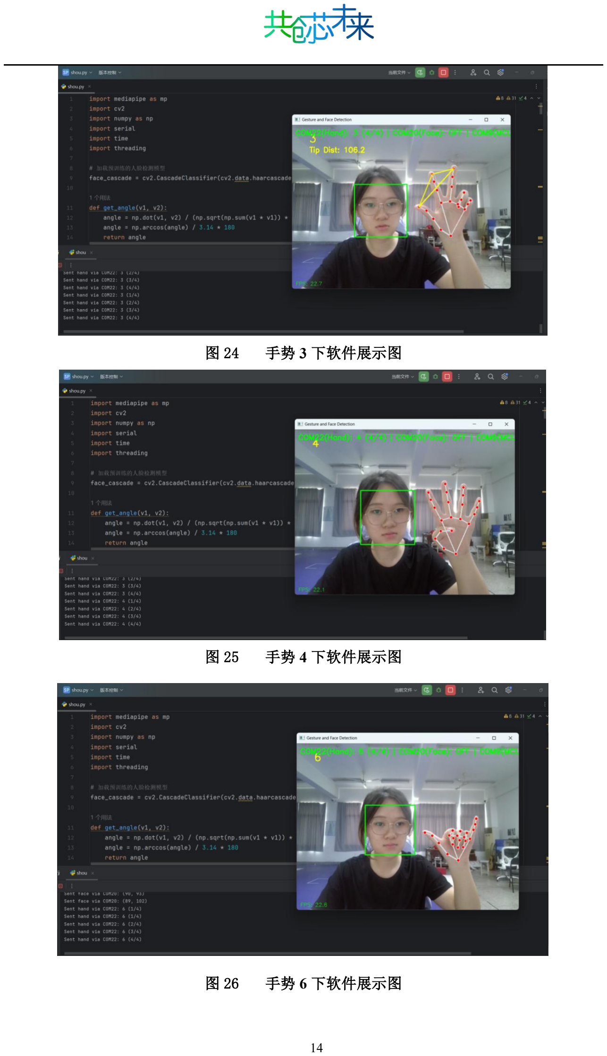
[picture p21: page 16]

图 24 | 手势 3 下软件展示图
图 25 | 手势 4 下软件展示图
图 26 | 手势 6 下软件展示图

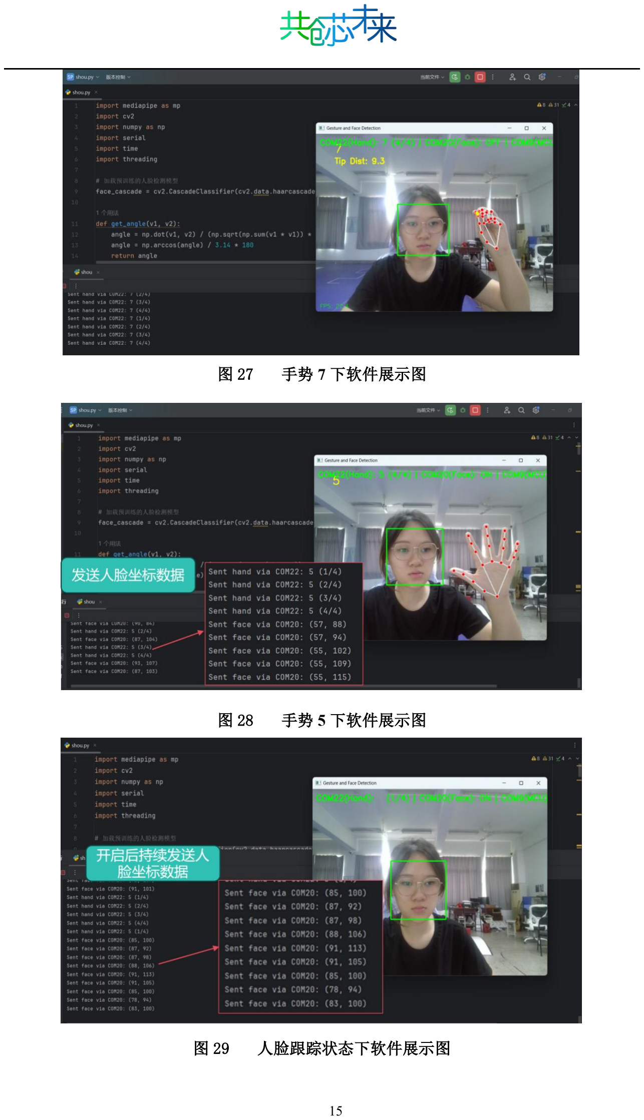
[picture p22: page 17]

图 27 | 手势 7 下软件展示图
图 28 | 手势 5 下软件展示图
图 29 | 人脸跟踪状态下软件展示图

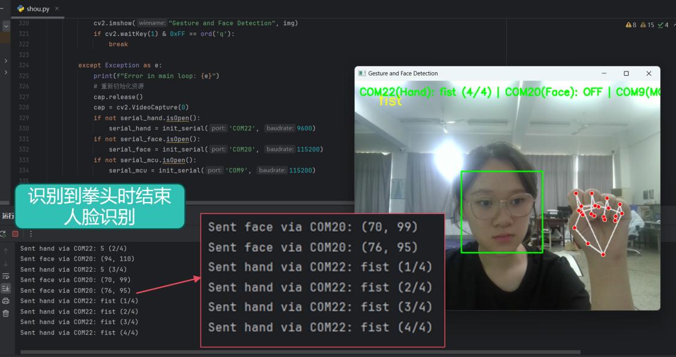
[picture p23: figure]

图 30 | 结束人脸跟踪的手势识别图

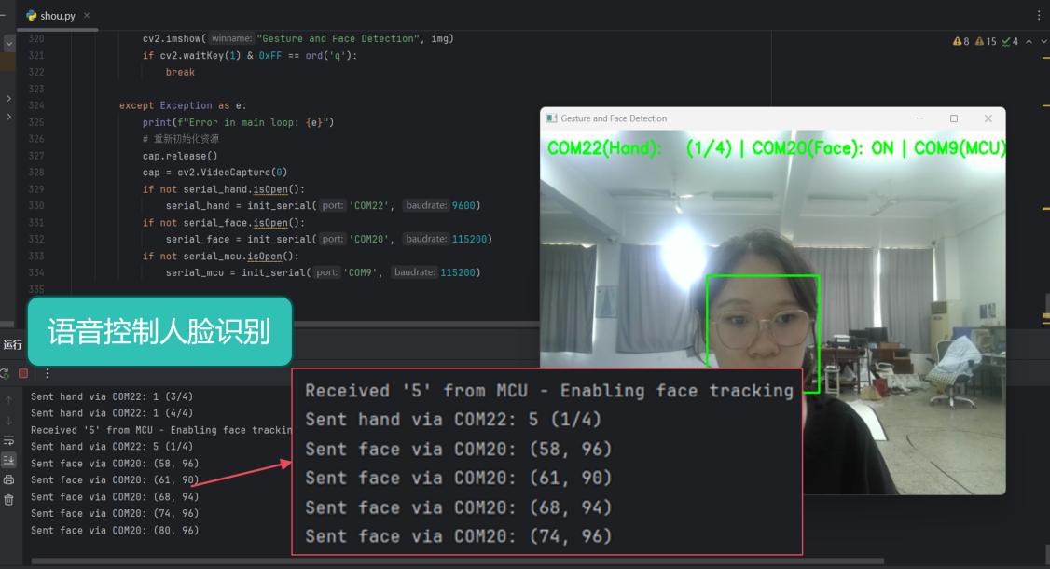
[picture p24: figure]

图 31 | 语音控制时 PC 端数据发送图

通过手机端连接蓝牙，接收框里便可自动接收相应的模式下的数据，并同时 保存，当模式 5 时，接收 PC 端识别到的人脸坐标。在不同的模式下，硬件模块 做出相应的反应。具体情况如下：

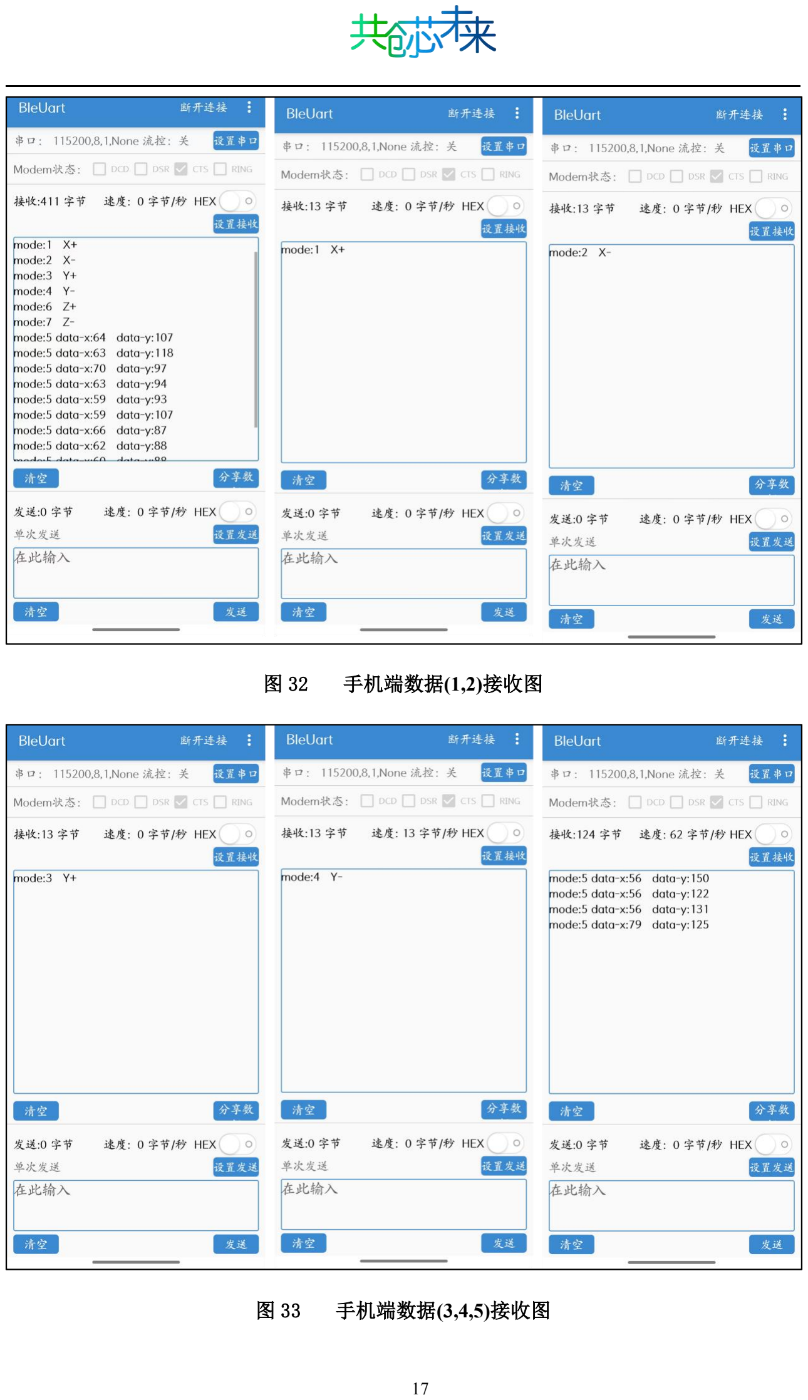
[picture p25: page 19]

图 32 | 手机端数据(1,2)接收图
图 33 | 手机端数据(3,4,5)接收图

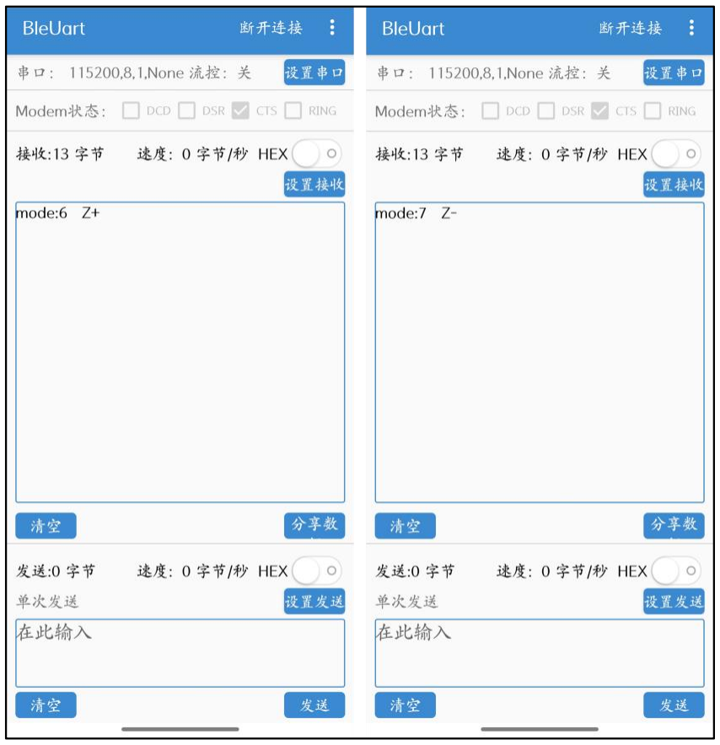
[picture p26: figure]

图 34 手机端数据(6,7)接收图

第四部分 总结

### 4.1 可扩展之处

(1) 功能扩展：可进一步集成更多传感器（如陀螺仪、加速度计）以提升稳像精 度，或加入环境光传感器实现自适应光线调节。同时，可扩展更多手势指令 或语音命令，增强交互多样性。
(2) 应用扩展：系统可适配无人机、机器人等移动平台，实现动态场景下的稳像 跟踪；也可应用于虚拟现实（VR）设备，通过手势和语音交互提升沉浸感。
(3) 智能化扩展：结合深度学习算法优化人脸跟踪的实时性与鲁棒性，或引入联 邦学习技术实现多设备协同优化。此外，可开发云端数据平台，实现远程监 控与大数据分析，进一步拓展系统的智能化应用场景。

### 4.2 心得体会

在这个夏天，有幸参加了一场嵌入式系统设计竞赛。这次竞赛不仅让我们深 入了解了嵌入式系统的设计与实现，还让我们在团队合作、问题解决以及项目管 理等方面得到了极大的提升。回顾整个参赛过程，充满了挑战和收获，每一步都 留下了深刻的印象。
在项目初期，我们遇到了许多困难。首先是硬件选择和搭建。我们需要选择 合适的控制器以及通信模块，并将它们有效地集成在一起。由于团队成员对硬件

的了解程度不同，我们花了大量时间进行讨论和学习。最终，我们决定使用 ch32v307 作为主控板，搭配三自由度云台模块，以及语音和蓝牙控制模块，外 加显示屏模块。
硬件选定后，接下来就是程序编写的艰难历程。嵌入式编程与普通的软件编 程有很大的不同，它需要考虑硬件的资源限制、实时性以及可靠性。在编写控制 程序的过程中，我们遇到了许多问题。例如，如何高效地采集串口通信传输数据， 如何相对稳定地控制舵机，如何处理多任务并发的问题，以及如何保证系统的稳 定性和响应速度。
除了软件编写，硬件调试也是一个不断试错的过程。我们采用 PID 算法进 行调试，使云台稳定工作，并且确保数据传输的稳定性。
经过努力，我们最终完成了稳像云台控制系统的设计和实现。虽然过程中遇 到了许多困难和挑战，但正是这些困难让我们不断学习和成长。通过这次竞赛， 不仅掌握了嵌入式系统设计的核心技术，还培养了团队合作和问题解决的能力。 总的来说，这次嵌入式竞赛受益匪浅。从硬件选择、程序编写到硬件调试， 每一步都充满了挑战和乐趣。最重要的是，学会了通过不断尝试和探索，最终找 到解决问题的方法。这些经历和体会将成为我们今后学习和工作的宝贵财富。

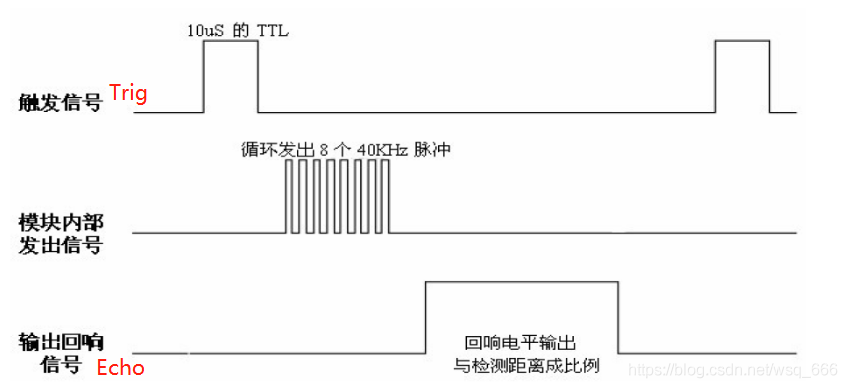
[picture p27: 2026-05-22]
竞赛资料/主控资料-ch32v307/CH32V307例程/2.24-HC-SR04超声波测距/2.24-HC-SR04超声波测距/HC-SR04时序图.png

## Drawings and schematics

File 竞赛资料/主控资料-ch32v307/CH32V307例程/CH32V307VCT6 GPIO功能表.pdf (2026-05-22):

# Date:2022/11/20

# REV:1.0

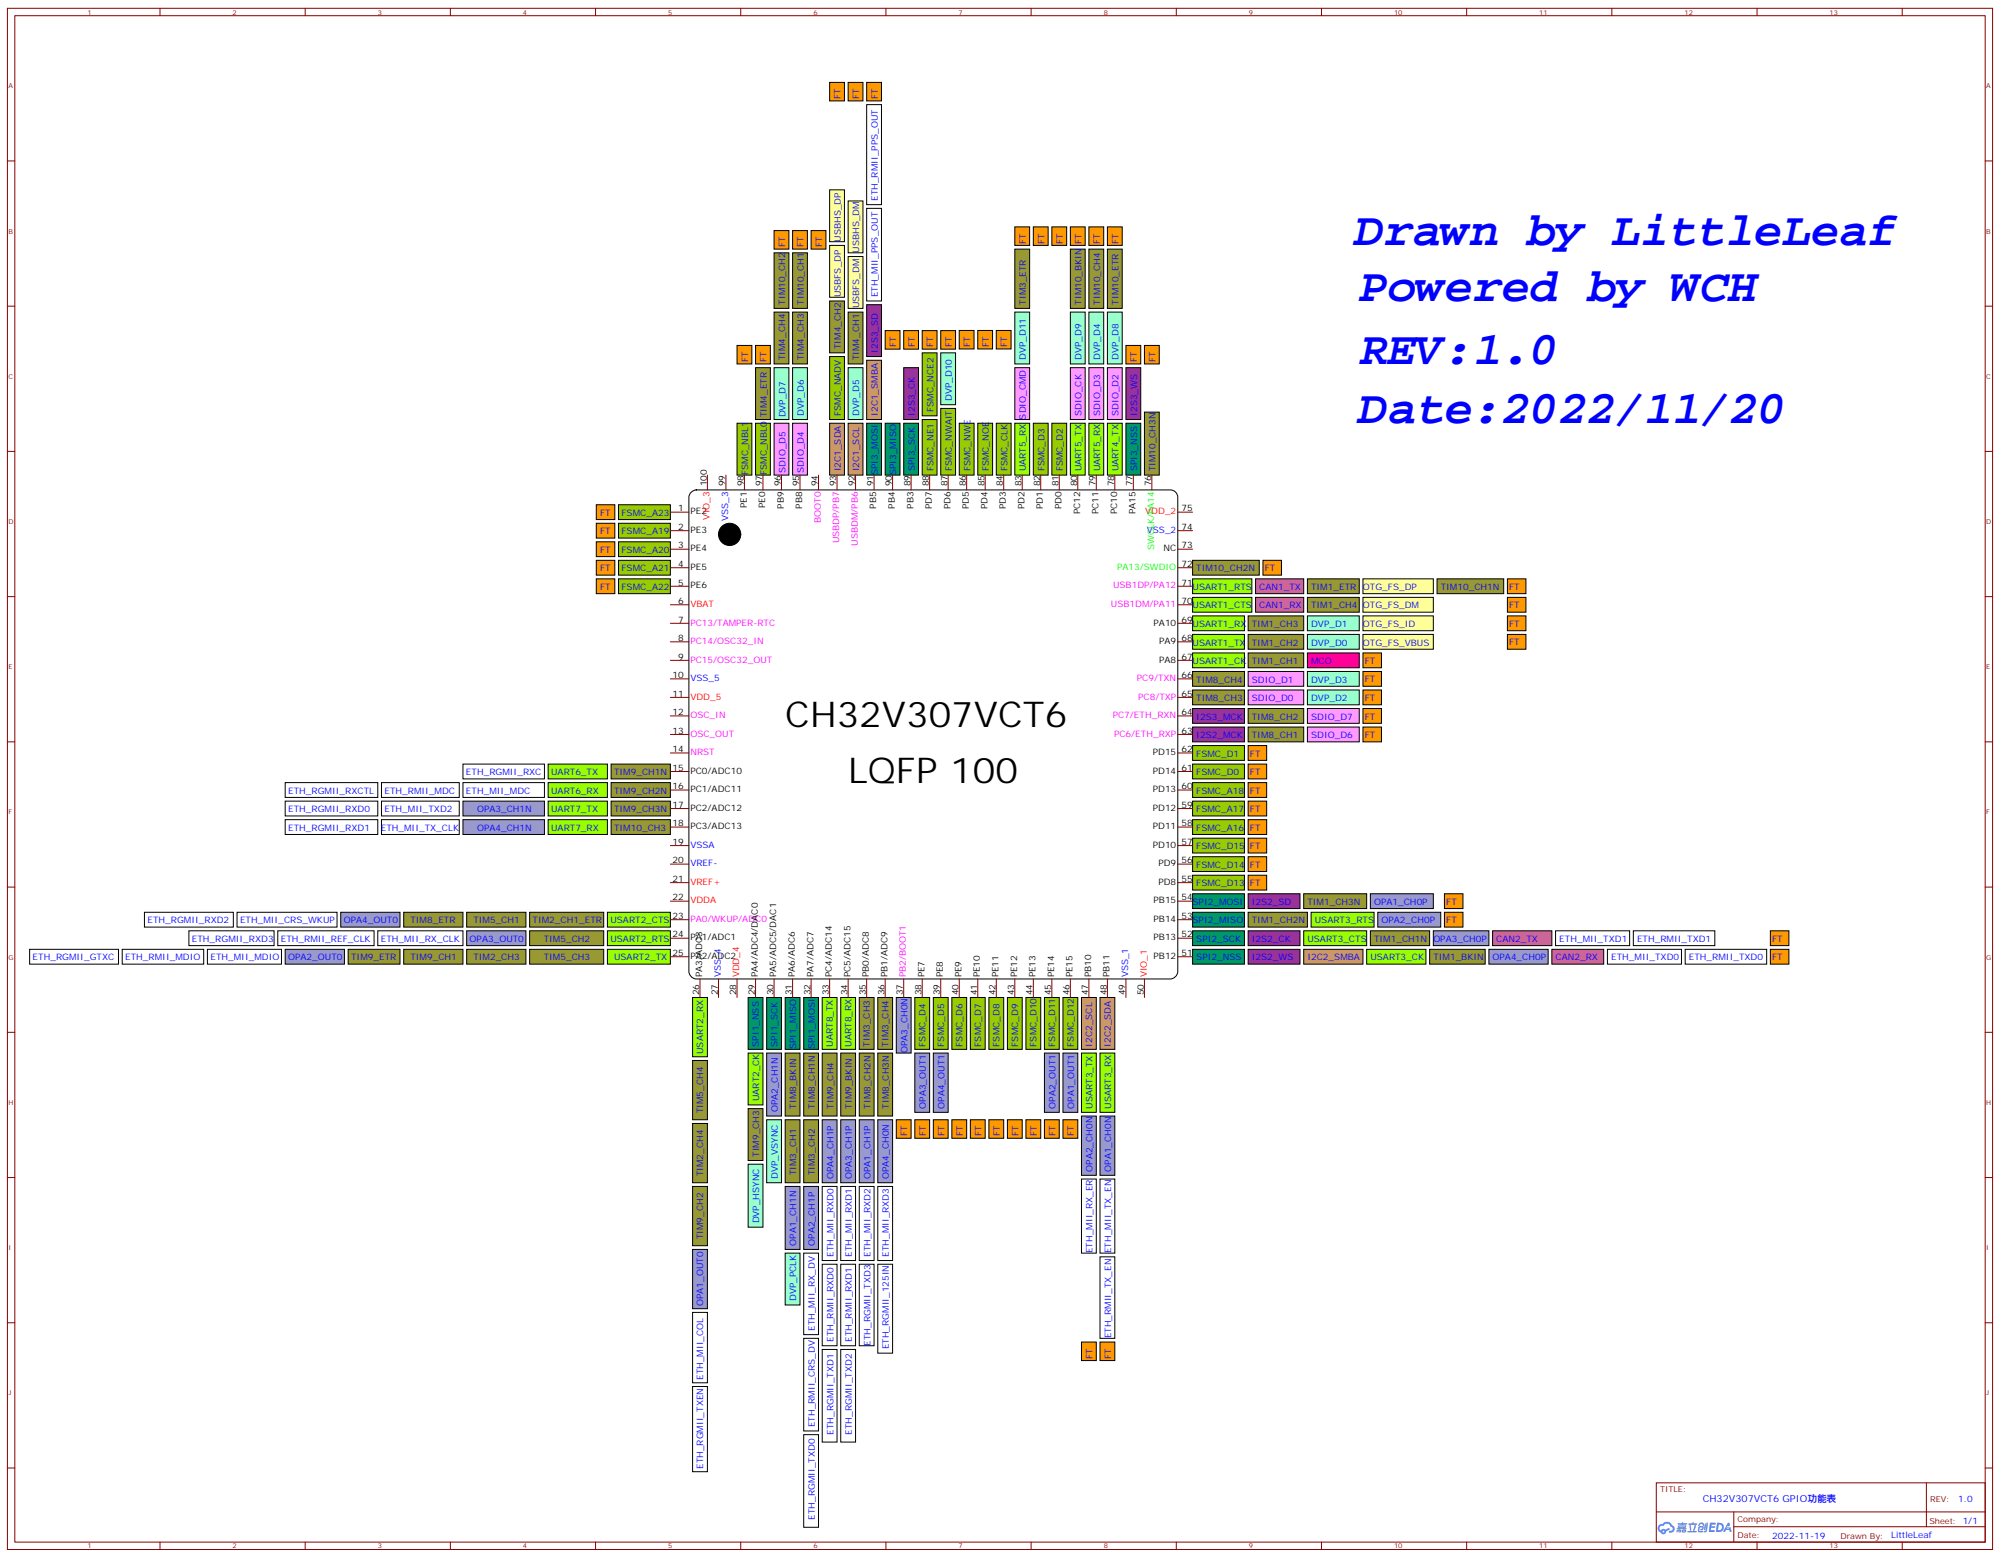
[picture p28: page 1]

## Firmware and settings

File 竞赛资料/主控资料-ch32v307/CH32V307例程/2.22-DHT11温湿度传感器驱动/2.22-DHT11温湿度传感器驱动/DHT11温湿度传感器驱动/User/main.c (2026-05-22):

/********************************** (C) COPYRIGHT *******************************
* File Name          : main.c
* Author             : WCH
* Version            : V1.0.0
* Date               : 2021/06/06
* Description        : Main program body.
* Copyright (c) 2021 Nanjing Qinheng Microelectronics Co., Ltd.
* SPDX-License-Identifier: Apache-2.0
*******************************************************************************/

/*
 *@Note
 串口打印调试例程：
 USART1_Tx(PA9)。
 本例程演示使用 USART1(PA9) 作打印调试口输出。

*/

#include "debug.h"
#include  "../General_Files/drivers/DHT11.h"
#include "../General_Files/drivers/ST7789.h"

#include "system.h"

/* Global typedef */

/* Global define */

/* Global Variable */


/*********************************************************************
 * @fn      main
 *
 * @brief   Main program.
 *
 * @return  none
 */
int main(void)
{
    NVIC_PriorityGroupConfig(NVIC_PriorityGroup_2);
    Delay_Init();
    USART_Printf_Init(115200);
    printf("SystemClk:%d\r\n",SystemCoreClock);

    printf("This is printf example\r\n");

    System_Init();
    while(1)
    {
          ST7789_ShowCHN(10,10, "湿度：", color_WHITE, color_BLACK, SIZE_CHN_32x32);
//        ST7789_ShowString(3*32+7*16, 32, "%RH", color_WHITE, color_BLUE, SIZE_ASCII_16x32);
//        ST7789_ShowNumf(96, 32, DHT11.humidity, 4, color_WHITE, color_BLACK, SIZE_ASCII_16x32);
//        ST7789_ShowCHN(0, 64, "温度：", color_WHITE, color_BLUE, SIZE_CHN_32x32);
//        ST7789_ShowNumf(96, 64, DHT11.temperature, 4, color_WHITE, color_BLACK, SIZE_ASCII_16x32);
//        ST7789_ShowCHN(3*32+7*16, 64, "℃", color_WHITE, color_BLUE, SIZE_CHN_32x32);
//        System_Loop();
    }
}

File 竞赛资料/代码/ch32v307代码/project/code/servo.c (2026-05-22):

#include "zf_common_headfile.h"


// 初始化所有舵机PWM
void Servo_PWM_Init_All(void) {
    // 50Hz PWM (周期20ms), 初始占空比1.5ms (中位)
    pwm_init(SERVO_X_PWM, 50, 1500 * PWM_DUTY_MAX / 20000);
    pwm_init(SERVO_Y_PWM, 50, 1500 * PWM_DUTY_MAX / 20000);
    pwm_init(SERVO_Z_PWM, 50, 1500 * PWM_DUTY_MAX / 20000);

    printf("[PWM] Initialized (50Hz)\n");
}

// 设置舵机角度 (0-180°)
void Servo_Set_Angle(Servo_Channel ch, uint8_t angle) {
    angle = angle > 180 ? 180 : angle; // 安全限制

    uint32_t pulse_us = 500 + angle * 2000 / 180;  // 0.5ms-2.5ms
    uint32_t duty = pulse_us * PWM_DUTY_MAX / 20000;

    switch(ch) {
        case SERVO_X: pwm_set_duty(SERVO_X_PWM, duty); break;
        case SERVO_Y: pwm_set_duty(SERVO_Y_PWM, duty); break;
        case SERVO_Z: pwm_set_duty(SERVO_Z_PWM, duty); break;
    }

}

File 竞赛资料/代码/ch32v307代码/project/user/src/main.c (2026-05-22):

#include "zf_common_headfile.h"
#include<stdio.h>
#include<math.h>
#include<string.h>
#include<stdlib.h>
int flag_num=1;
uint8 test=10;
int cmd1;
uint32_t last_pid_time = 0;
#define PID_INTERVAL 20 // 20ms控制周期


int main(void)
{
        clock_init(SYSTEM_CLOCK_144M);      // 务必保留，设置系统时钟。
//      debug_init();                       // 务必保留，本函数用于初始化MPU 时钟 调试串口
        Kang_init();
        uart_init(UART_8, 9600, UART8_MAP0_TX_C4, UART8_MAP0_RX_C5); //接收数字数据
        uart_init(UART_6, 115200, UART6_MAP3_TX_E10, UART6_MAP3_RX_E11);//接收坐标数据
        uart_init(UART_5, 9600, UART5_MAP0_TX_C12, UART5_MAP0_RX_D2);//接收语音数据
        uart_init(UART_4, 115200, UART4_MAP0_TX_C10, UART4_MAP0_RX_C11);//发送语音给python
        uart_init(UART_1, 19200, UART1_MAP0_TX_A9 , UART1_MAP0_RX_A10);//语音播报
        uart_rx_interrupt(UART_5, ENABLE);
         uart_rx_interrupt(UART_8, ENABLE);
        uart_rx_interrupt(UART_6, ENABLE);
        uart_rx_interrupt(UART_4, ENABLE);
        uart_rx_interrupt(UART_1, ENABLE);
        // 此处编写用户代码 例如外设初始化代码等

        // 替代 clock() 的调用
        tft180_show_chinese (2, 5, 16, tft_chinese[0],4, RGB565_RED);//欢迎来到
        tft180_show_chinese (10, 27, 16, tft_chinese[8],6, RGB565_RED);//稳像云台系统
        tft180_draw_line(5,50, 120,50,RGB565_RED);      // 坐标 0,0 到 10,10 画一条红色的线
        tft180_show_string(0,55, "mode:");
        Beep_Init();

        while(1)
        {

            uart_control();
            tft180_show_int(40,55,CMD,2);
            Process_Command(CMD);
            uaaart();
            //uaaaart();
            // 设置舵机
            Servo_Set_Angle(SERVO_X, current_angle[0]);
            Servo_Set_Angle(SERVO_Y, current_angle[1]);
            Servo_Set_Angle(SERVO_Z, current_angle[2]);

        }

   }

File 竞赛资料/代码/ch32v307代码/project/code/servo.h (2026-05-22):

#ifndef __SERVO_H
#define __SERVO_H


#include "zf_common_headfile.h"

// 舵机通道定义
typedef enum {
    SERVO_X = 0,  // X轴
    SERVO_Y,      // Y轴
    SERVO_Z       // Z轴
} Servo_Channel;

// PWM通道配置（根据实际硬件连接修改）
#define SERVO_X_PWM   TIM2_PWM_MAP0_CH1_A0
#define SERVO_Y_PWM   TIM2_PWM_MAP0_CH2_A1
#define SERVO_Z_PWM   TIM2_PWM_MAP0_CH3_A2

// 函数声明
void Servo_PWM_Init_All(void);
void Servo_Set_Angle(Servo_Channel ch, uint8_t angle);

#endif

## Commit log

2026-05-22 feat: 初始化 CH32V307 稳像云台控制系统项目
    - 基础工程框架搭建，基于 CH32V307 微控制器
    - 集成正点原子底层驱动库（SDK、ZF 驱动、外设驱动等）
    - 实现 PID 控制、舵机驱动、蓝牙通信等核心功能模块
    - 包含竞赛参考资料（CH32V307 EVT 例程、教程文档）
    - 添加项目介绍文档及演示视频
    [9100带功放(AD).PcbDoc, 9101带功放(AD).PcbDoc, CH32F&Vx0xR-R1-1v2.PcbDoc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]
2026-06-14 docs: 重写README项目文档，添加详细的项目介绍和技术说明
2026-06-14 docs: 优化README文档格式，将中文ASCII图表转换为英文以提高兼容性

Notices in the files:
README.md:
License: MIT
